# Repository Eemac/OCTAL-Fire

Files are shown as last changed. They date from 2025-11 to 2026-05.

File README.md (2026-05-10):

# OCTAL-Fire
The largest collegiate-built drone in the world!
[OCTAL Website!](https://octalfire.com/)

THE DRONE

## What/Why is this project?
OCTAL is engineered to respond to wildfires faster--and safer--than humans can. Satellites can already detect hotspots with a resolution of ~500ft. Our system will autonomously deploy to the detected hotspot, perform an analysis with 6 visible and infrared-spectrum cameras, and release retardant before the fire has time to get large, saving wildlife, property, and human lives. With four 66Ah, 60V solid-state LiPo battery packs, a 120kg payload, and a projected 40-minute flight time, OCTAL is built smart, tough, and versatile.

## Commands for power-up on the CANable:
- sudo slcand -f -o -s6 -S 115200 -t hw /dev/ttyACMX can0
- sudo ip link set can0 up
- candump can0
- cansniffer -t 0 can0 (-t 0 will display all messages)
- cansend can0

## CANable Web Flasher:
[Link Here](https://canable.io/updater/canable2.html)

## Directory Structure:
### Root

| Path | Description |
|---|---|
| `Firmware/` | Embedded firmware for flight systems, BMS, charger, and CAN communication. |
| `Hardware/` | KiCad PCB designs, fabrication outputs, and mechanical files. |
| `libraries/` | Shared KiCad symbols, footprints, and 3D models. |
| `Software (Sensing)/` | Placeholder for sensing-side software. |
| `Software (Base Station)/` | Placeholder for base station software. |
| `README.md` | Main project overview. |

---

### Firmware/
Main embedded software tree.

| Path | Description |
|---|---|
| `Core/` | Main flight controller firmware. |
| `BMS/` | Battery Management System firmware. |
| `Charger/` | Charger controller firmware. |
| `can_api/` | Python CAN code-generation tools. |
| `libraries/` | Embedded driver libraries. |
| `can_lib.dbc` | CAN database definitions. |
| `x11.dbc` | Additional CAN message definitions. |
| `requirements.txt` | Python dependencies. |
| `run.sh` | Build script. for CAN message functions |

### Firmware/can_api/

Python tooling for generating CAN interfaces.

| File | Description |
|---|---|
| `c_generator.py` | Generates C CAN interface code. |
| `dbc_generator.py` | Generates DBC files. |
| `yaml_handler.py` | Parses YAML definitions. |
| `utils.py` | Shared helper functions. |
| `tests/` | Unit tests for generators. |
| `files/c_templates/` | Templates for generated C code. |

---

### Hardware/

PCB and electrical hardware designs.

| PCB / Project | Description |
|---|---|
| `Core/flight-core` | Main flight controller and avionics motherboard integrating STM32 control, CAN routing, power conversion, Cube interface logic, and system interconnects. |
| `BMS/` | Battery Management System board handling cell monitoring, balancing, thermistor sensing, fan control, and high-voltage battery telemetry. |
| `Power Board/` | High-current power distribution board for routing battery power to vehicle subsystems and monitoring thermal/load conditions. |
| `PowerFet/` | High-side MOSFET switching board for controllable power distribution and subsystem shutdown protection. |
| `Charger/` | Dedicated battery charger controller board with onboard regulators, USB-C input handling, and programmable charge control circuitry. |
| `GroundRing/` | Ground-distribution PCB intended to centralize system grounding and reduce high-current return path issues. |
| `Cube-Flipper/` | Adapter/interface board for Cube flight controller mounting or signal rerouting. |
| `Power Board/Thermistors/` | Small thermistor sensing daughterboard used for distributed temperature monitoring. |
| `Coaster/` | Small auxiliary/demo PCB project included in the repository. |
---

### libraries/

Shared KiCad libraries.

| Path | Description |
|---|---|
| `3DModels/` | STEP/STP component models. |
| `OlinBAD.pretty/` | Custom PCB footprints. |
| `parts/` | Symbols, footprints, datasheets, and docs. |
| `OlinBAD.kicad_sym` | KiCad symbol library. |

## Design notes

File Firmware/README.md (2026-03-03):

# OlinBAD
A BADass Firefighting Drone

## BEFORE LOADING FIRMWARE:
1. Run: `python3 venvStart.py` to create a python virtual environment
2. Start that environment with `source ./venv/bin/activate` (./ being the Firmware directory)
3. Build the dbc intermediate by running `python3 can_api/dbc_generator.py BMS/bms.yml`
3. Build the CAN C files by running `python3 can_api/c_generator.py -y BMS/bms.yml -d out.dbc -c can_api/files/c_templates/can.c -H can_api/files/c_templates/can.h -o BMS`

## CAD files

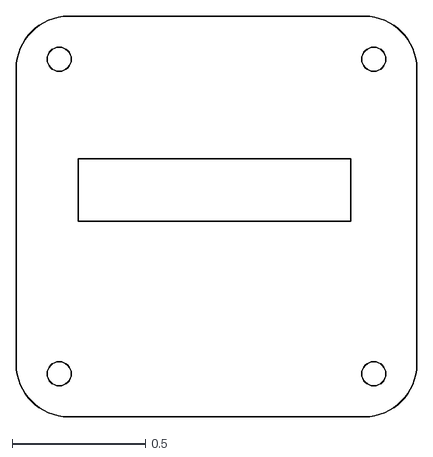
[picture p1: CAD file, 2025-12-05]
Hardware/Core/Bottom Of Cube.dxf
1.50 x 1.50

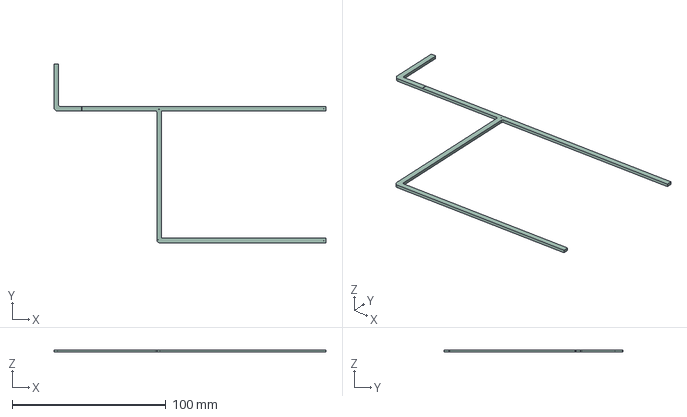
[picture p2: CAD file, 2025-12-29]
Hardware/Power Board/Thermistors/Thermistors.step
177.1 x 116.4 x 1.58 mm
Thermistors_silkscreen
Thermistors_PCB

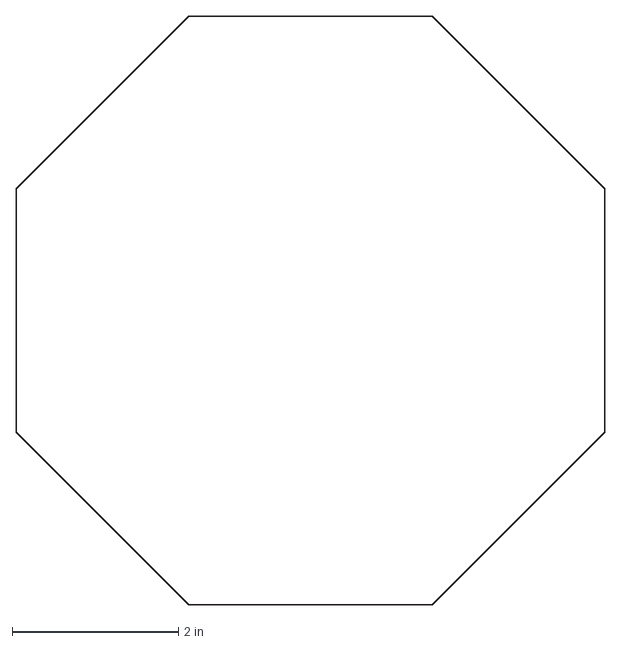
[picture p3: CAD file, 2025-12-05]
Hardware/Core/motherboard.dxf
7.09 x 7.09 in

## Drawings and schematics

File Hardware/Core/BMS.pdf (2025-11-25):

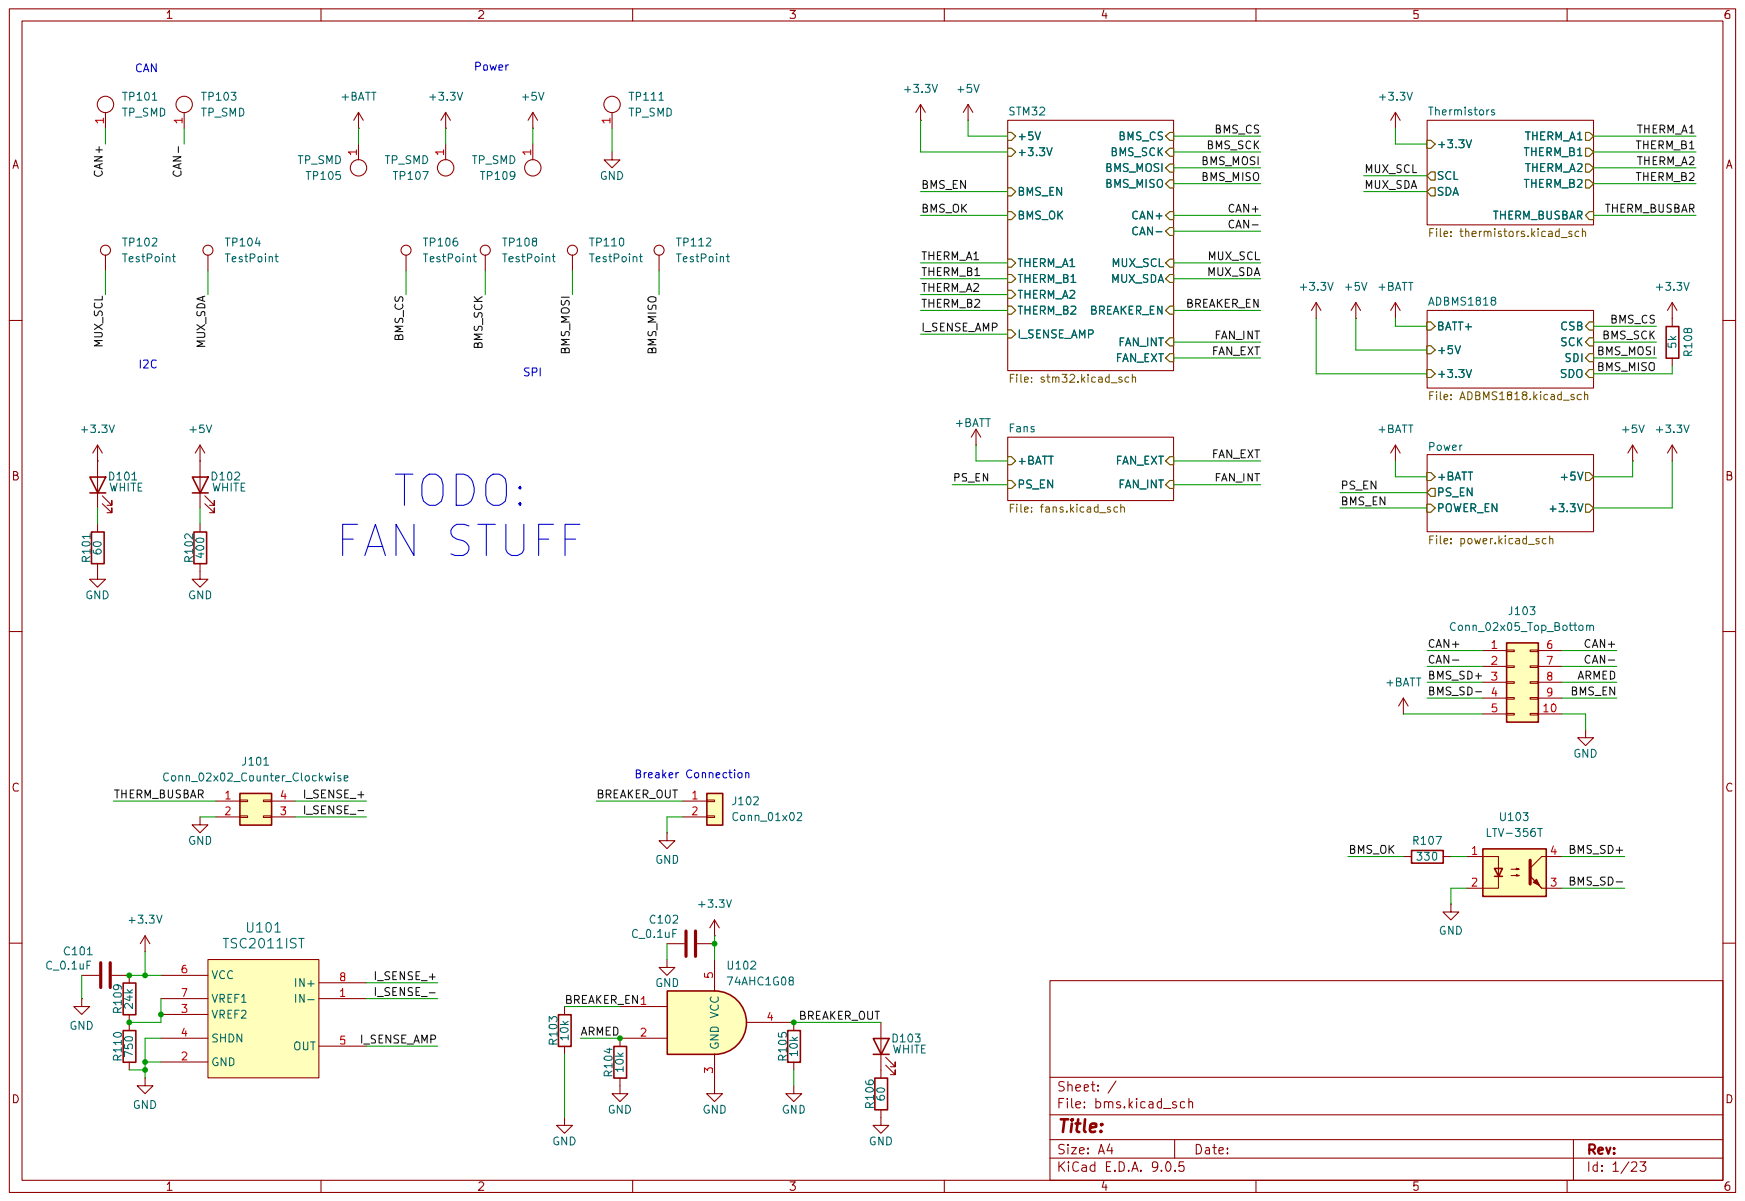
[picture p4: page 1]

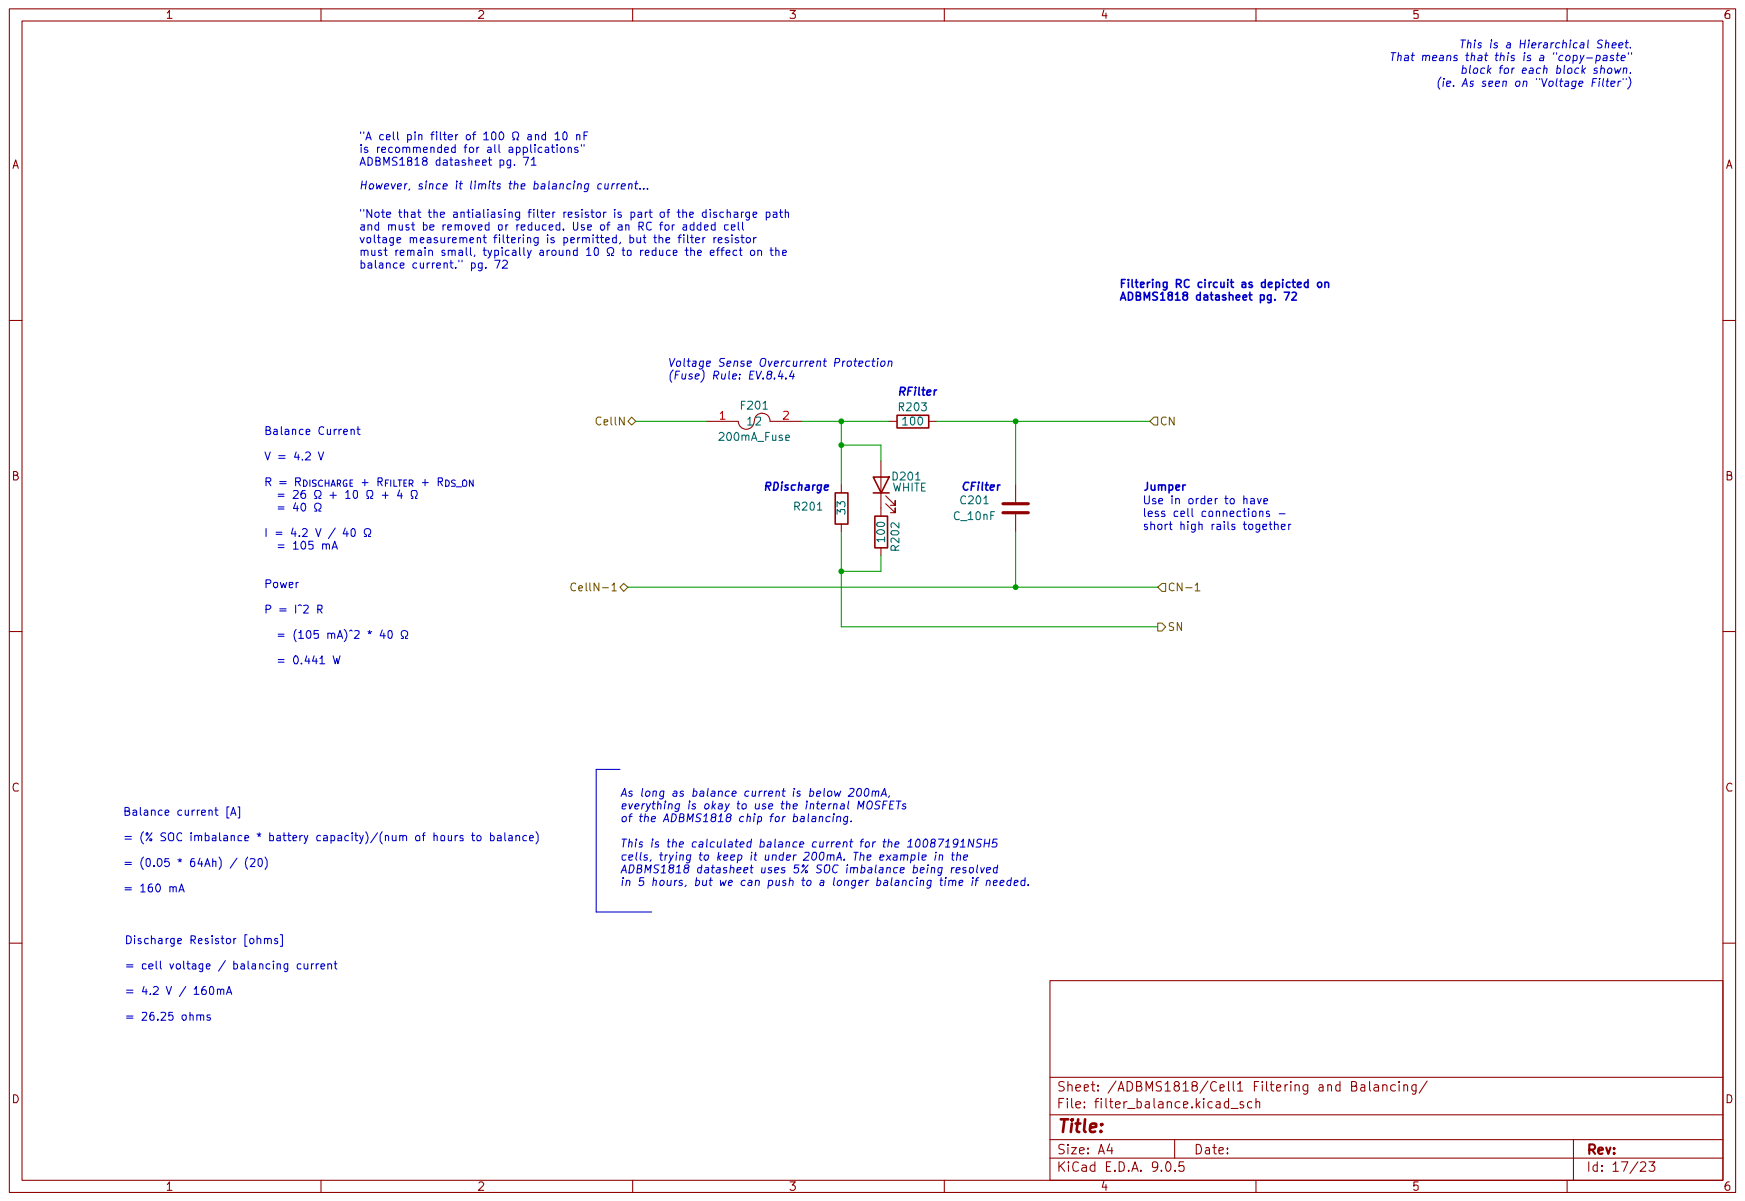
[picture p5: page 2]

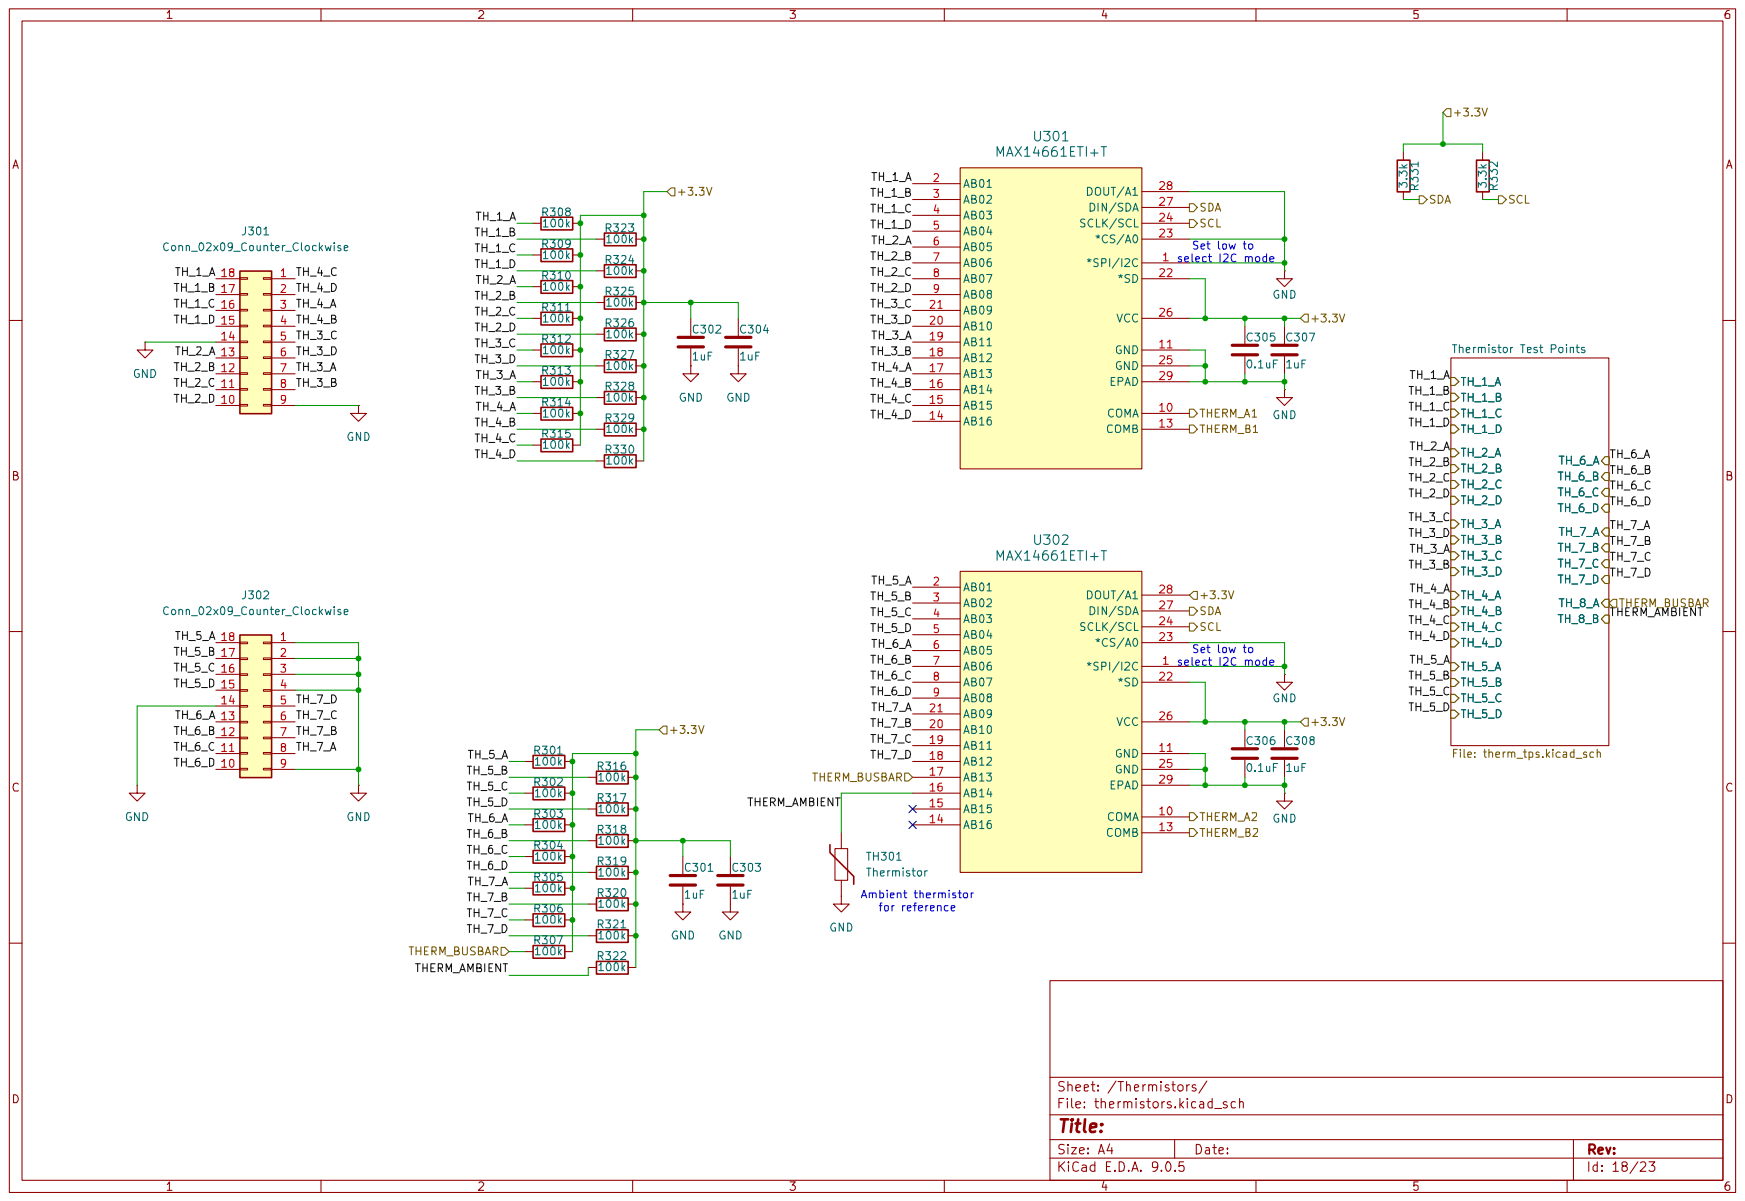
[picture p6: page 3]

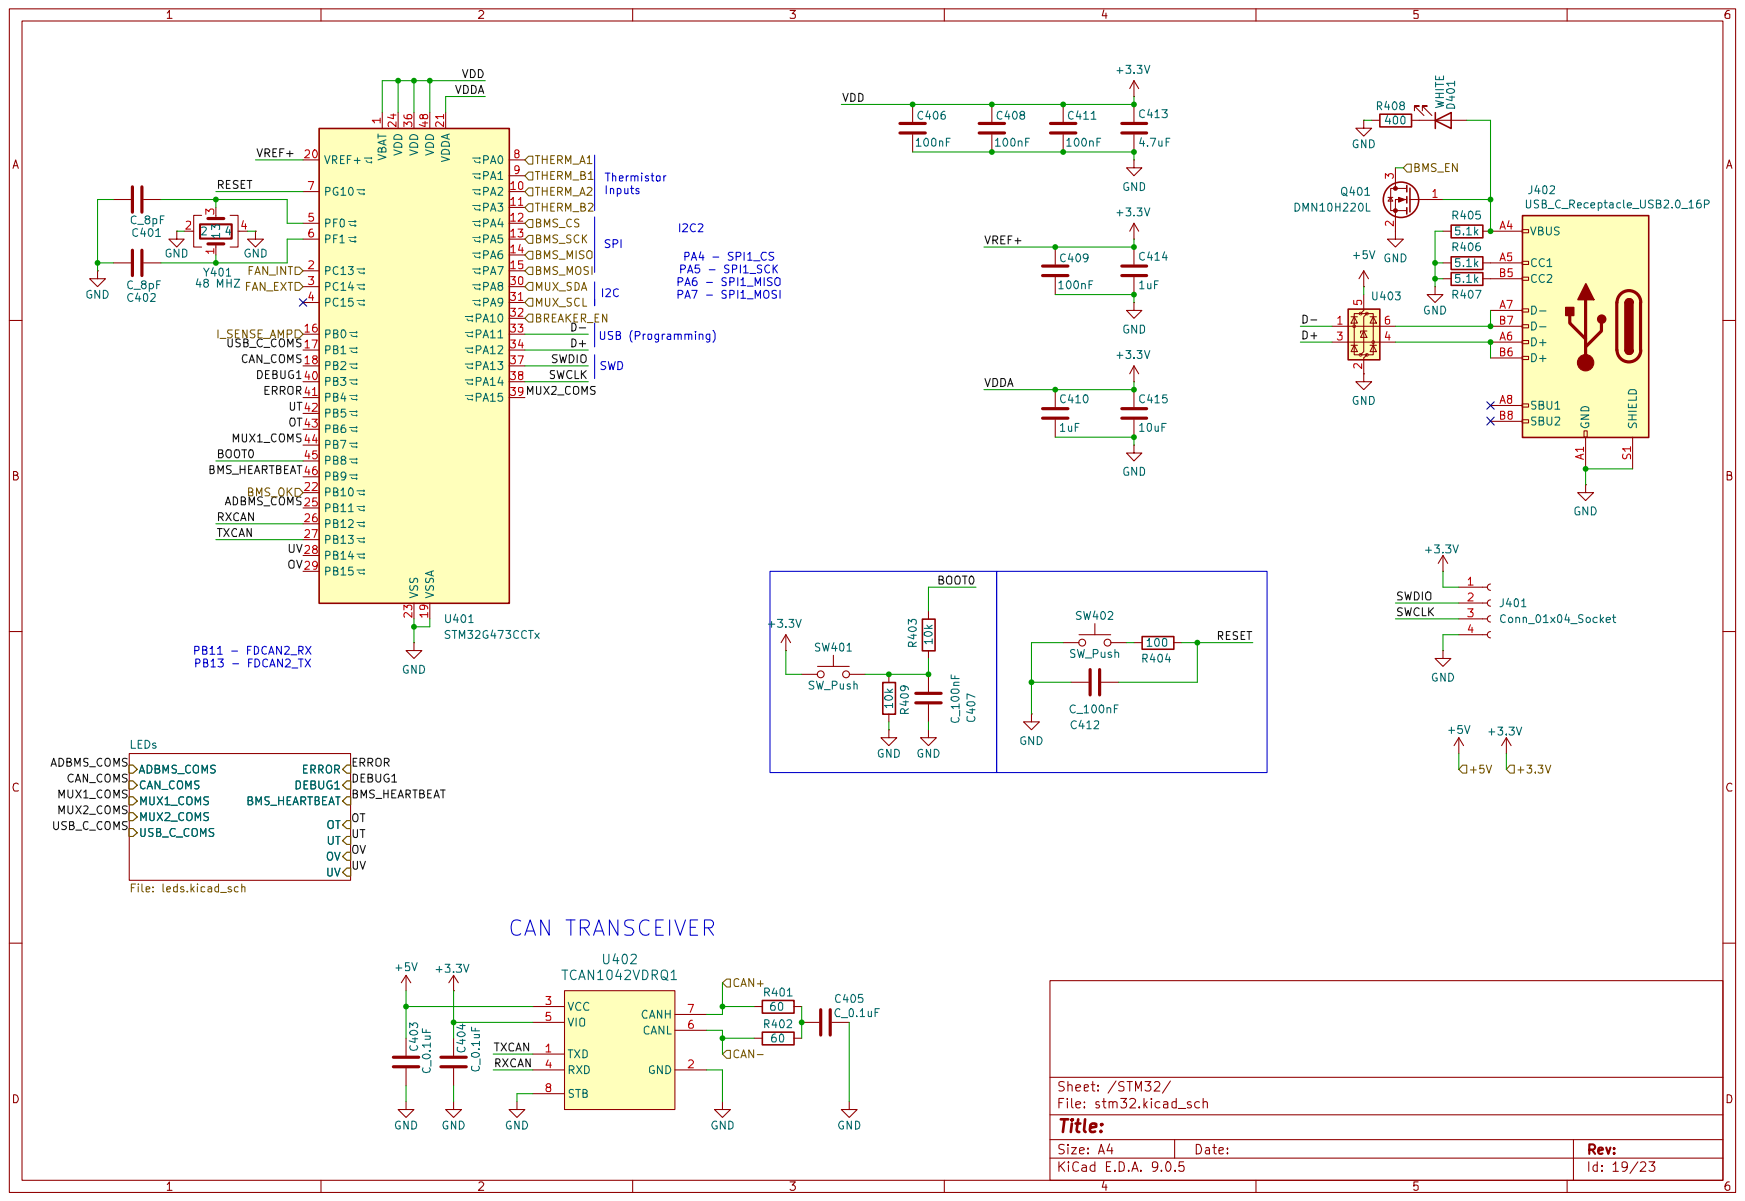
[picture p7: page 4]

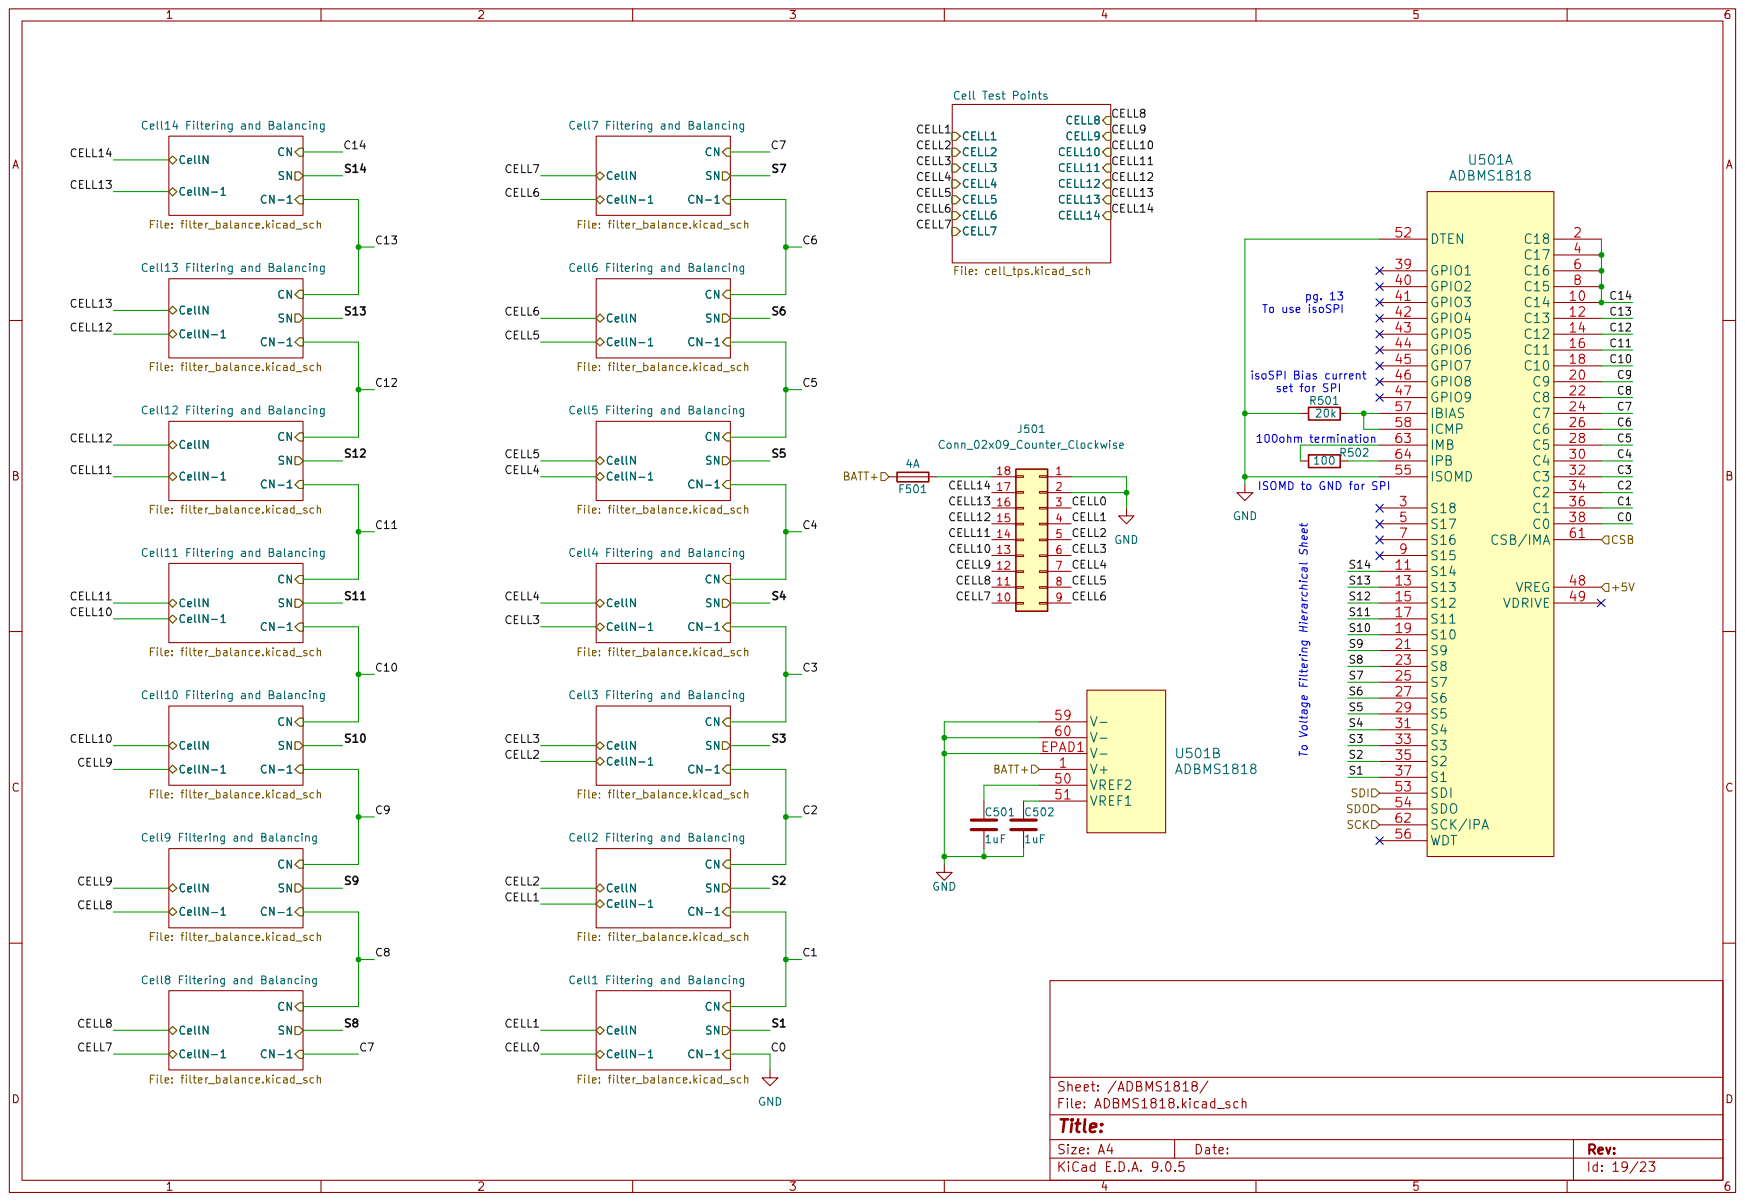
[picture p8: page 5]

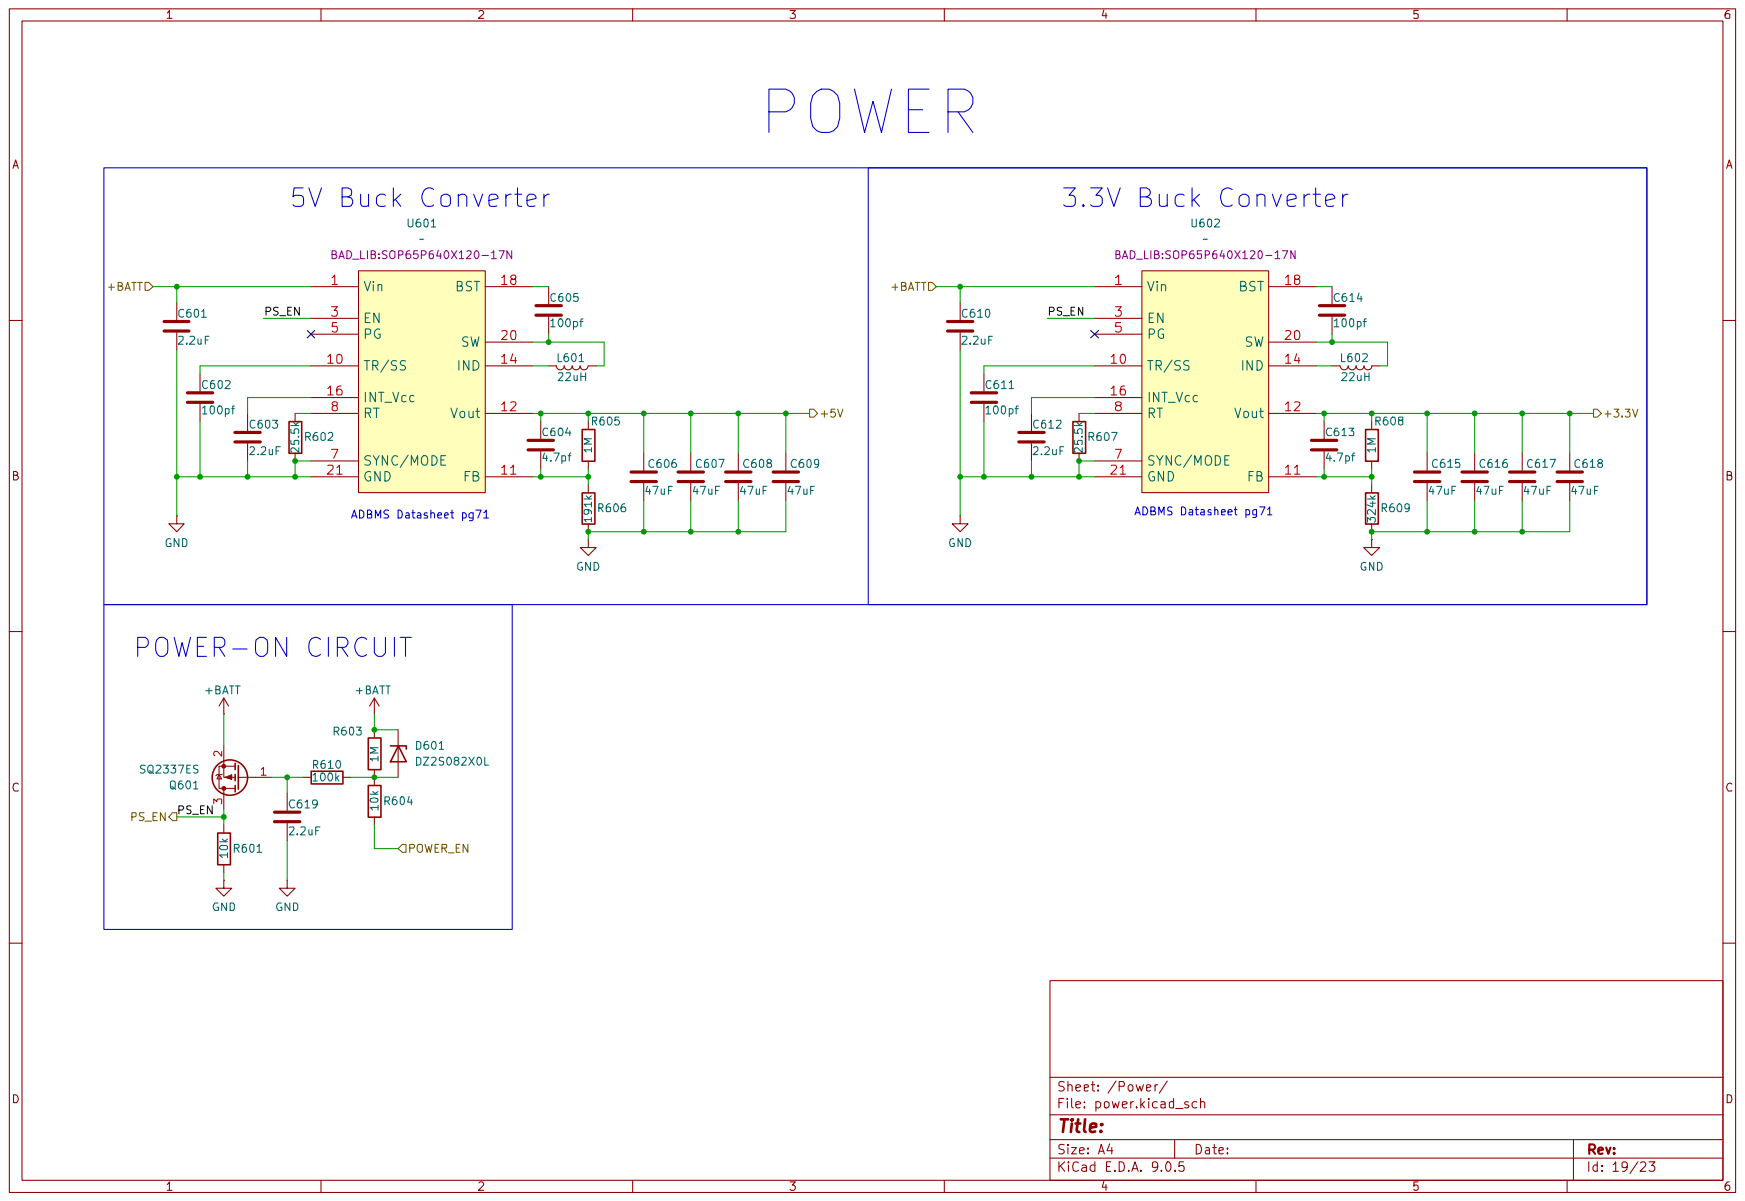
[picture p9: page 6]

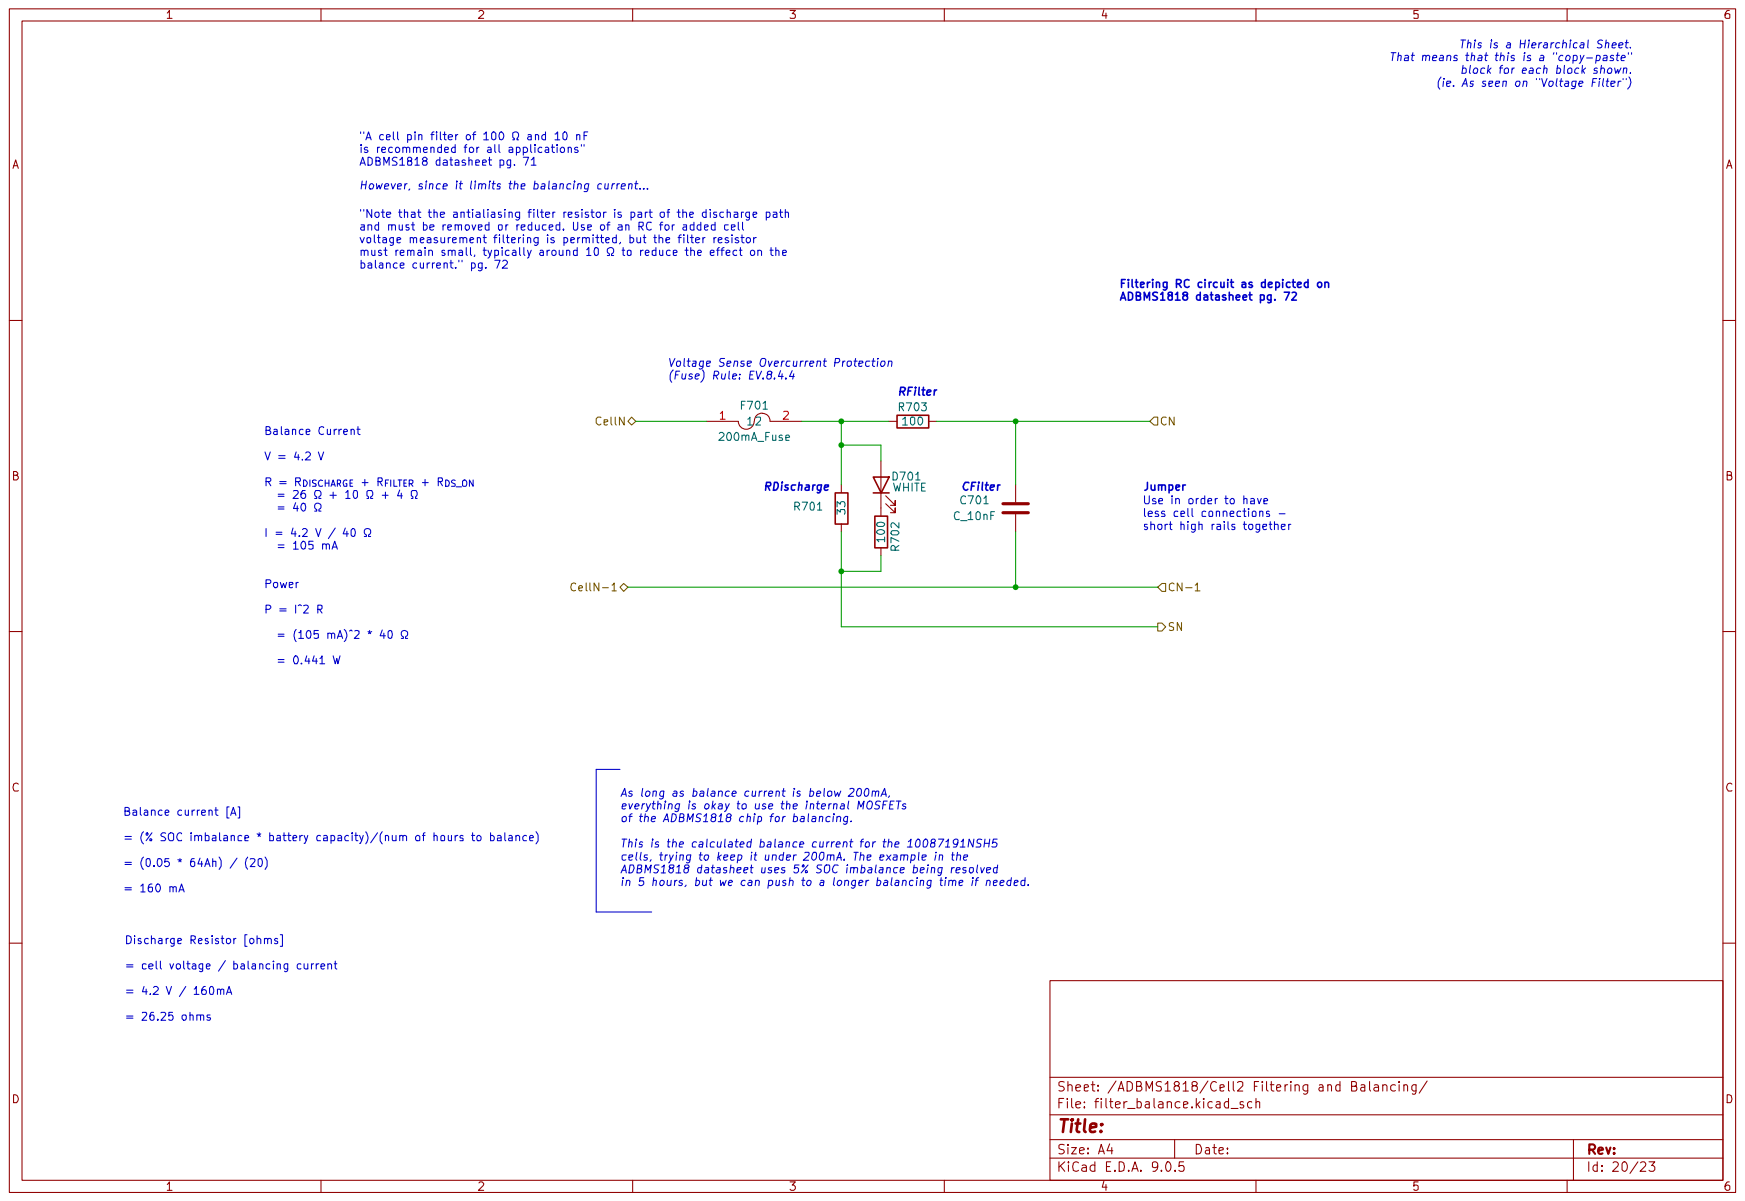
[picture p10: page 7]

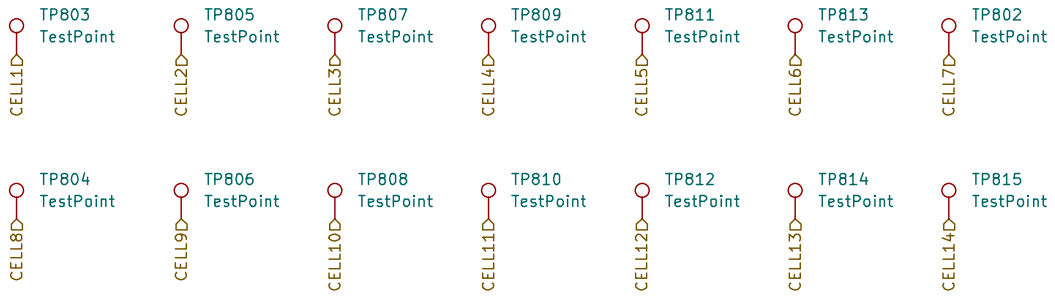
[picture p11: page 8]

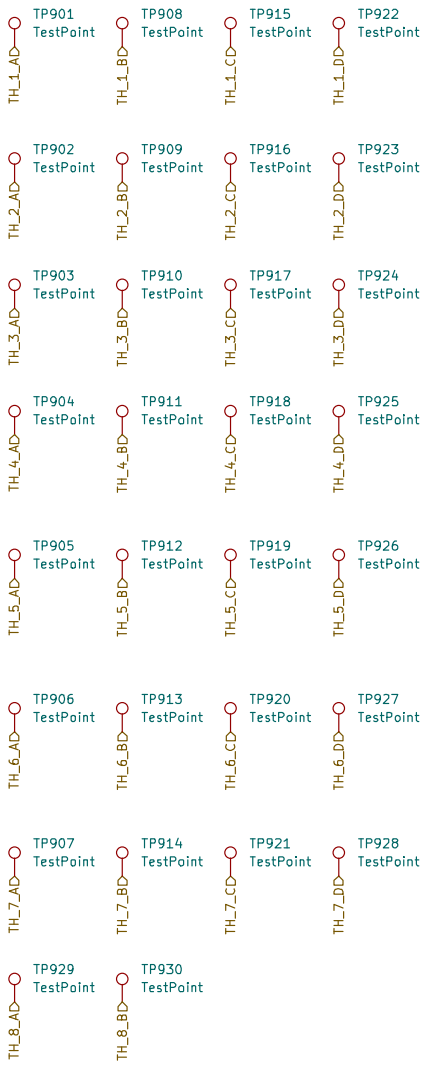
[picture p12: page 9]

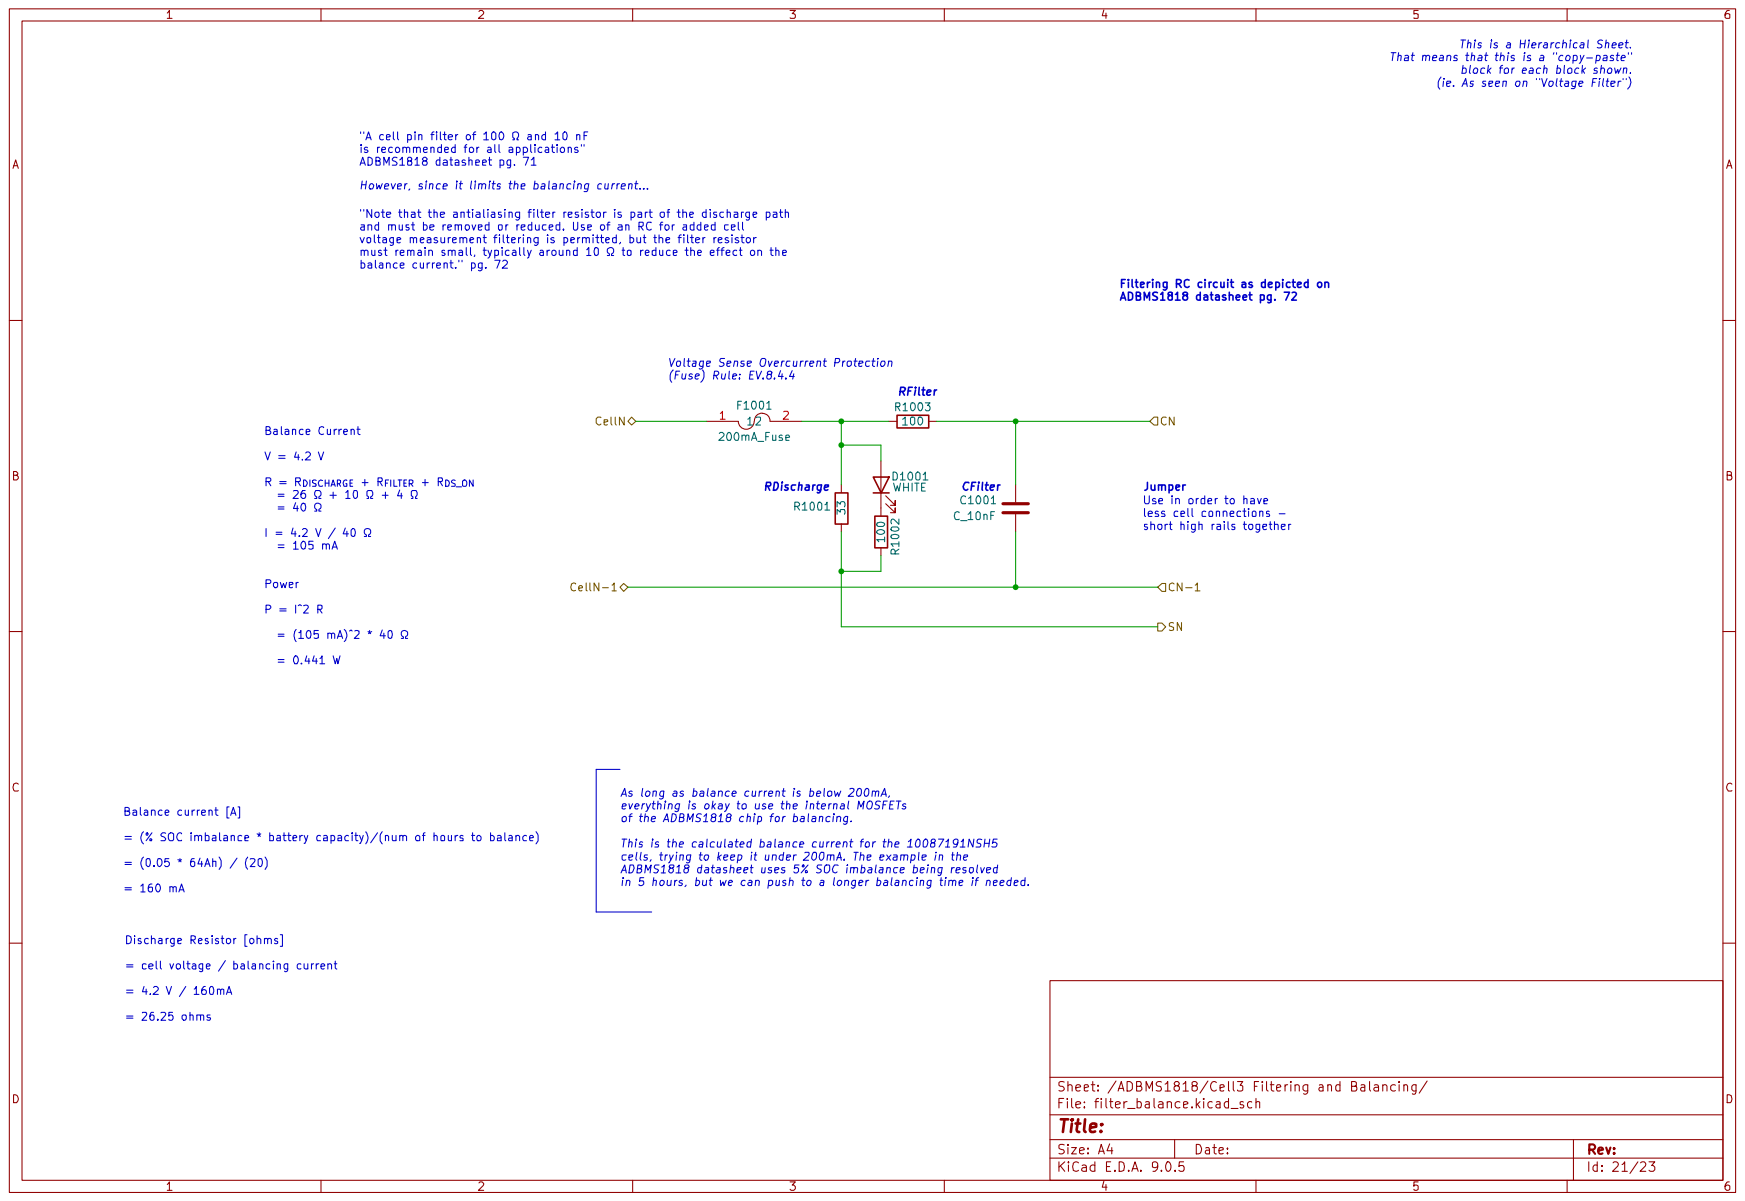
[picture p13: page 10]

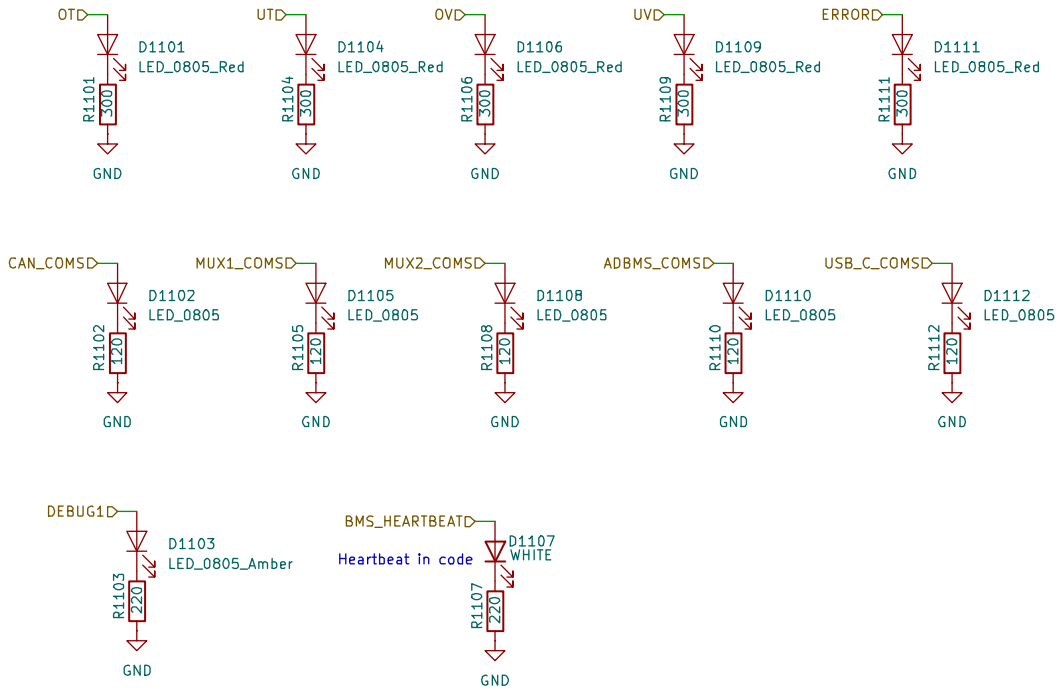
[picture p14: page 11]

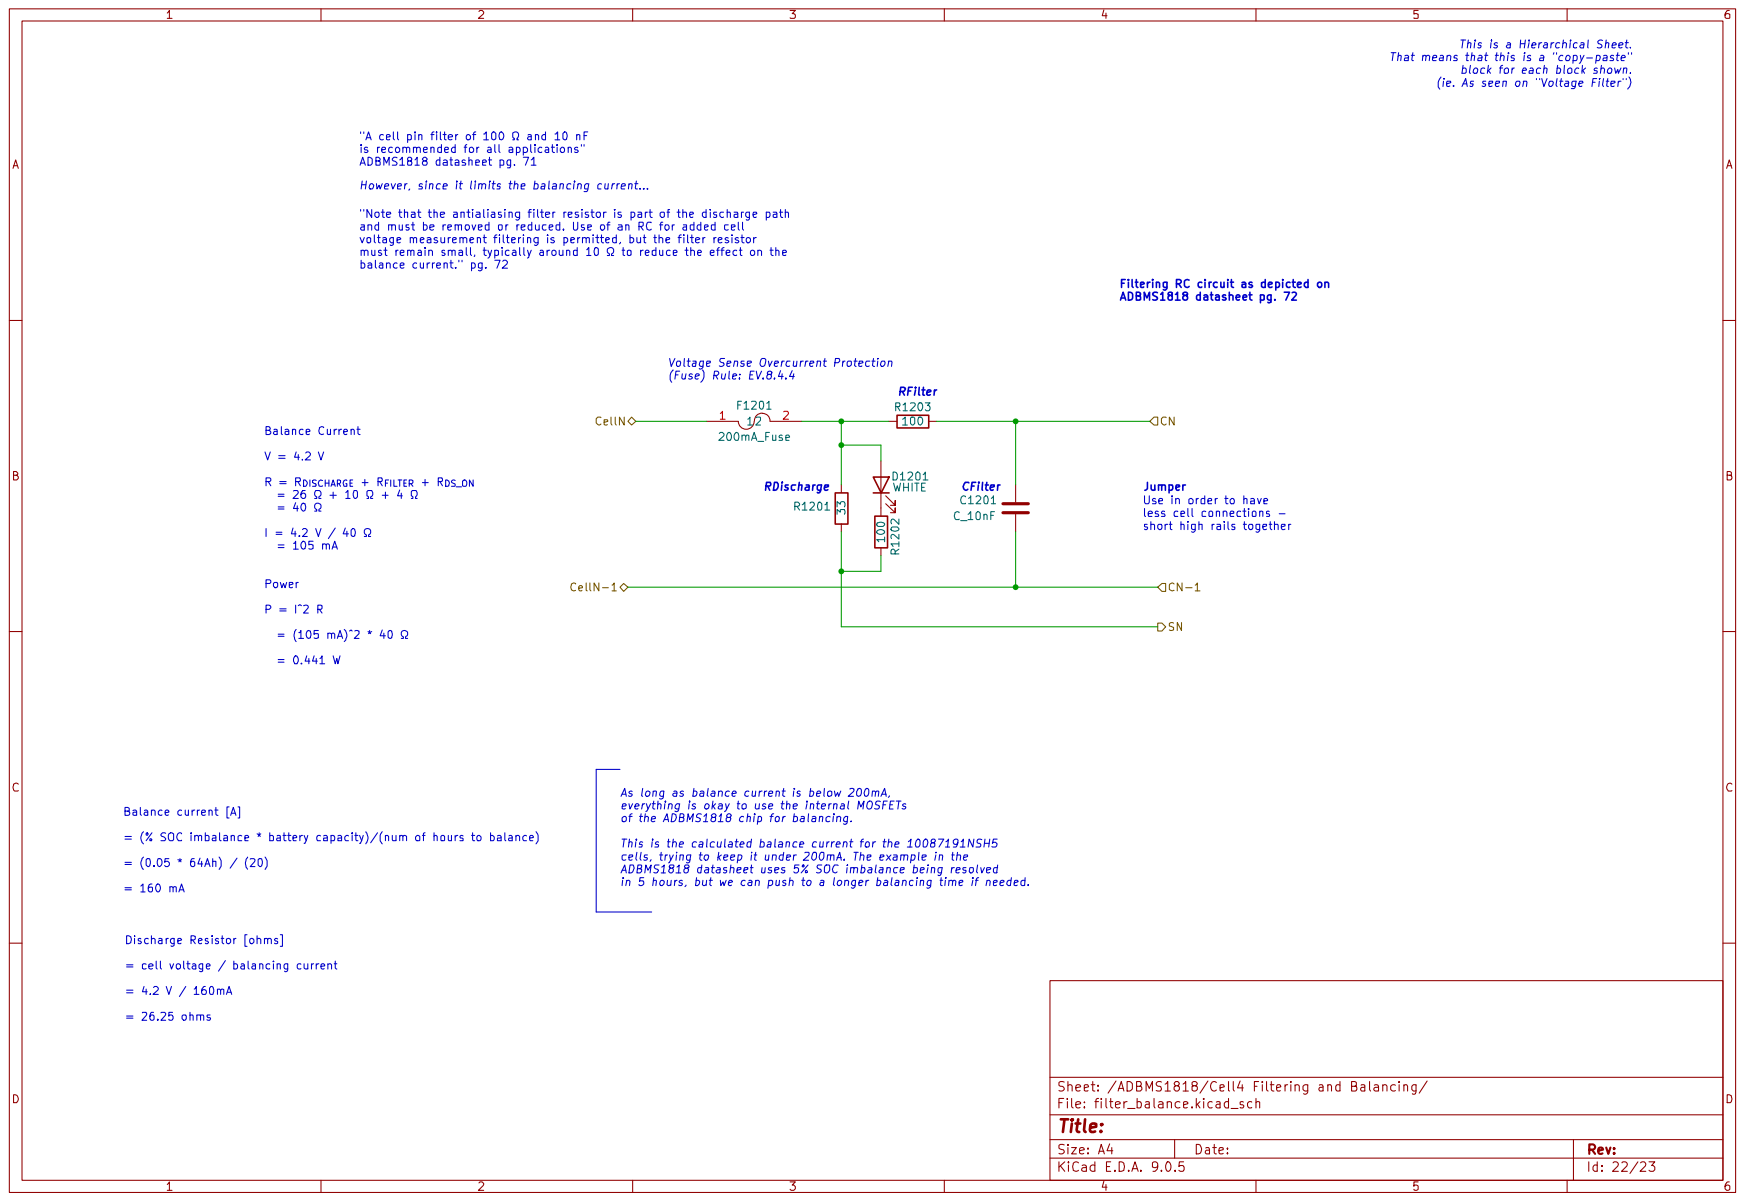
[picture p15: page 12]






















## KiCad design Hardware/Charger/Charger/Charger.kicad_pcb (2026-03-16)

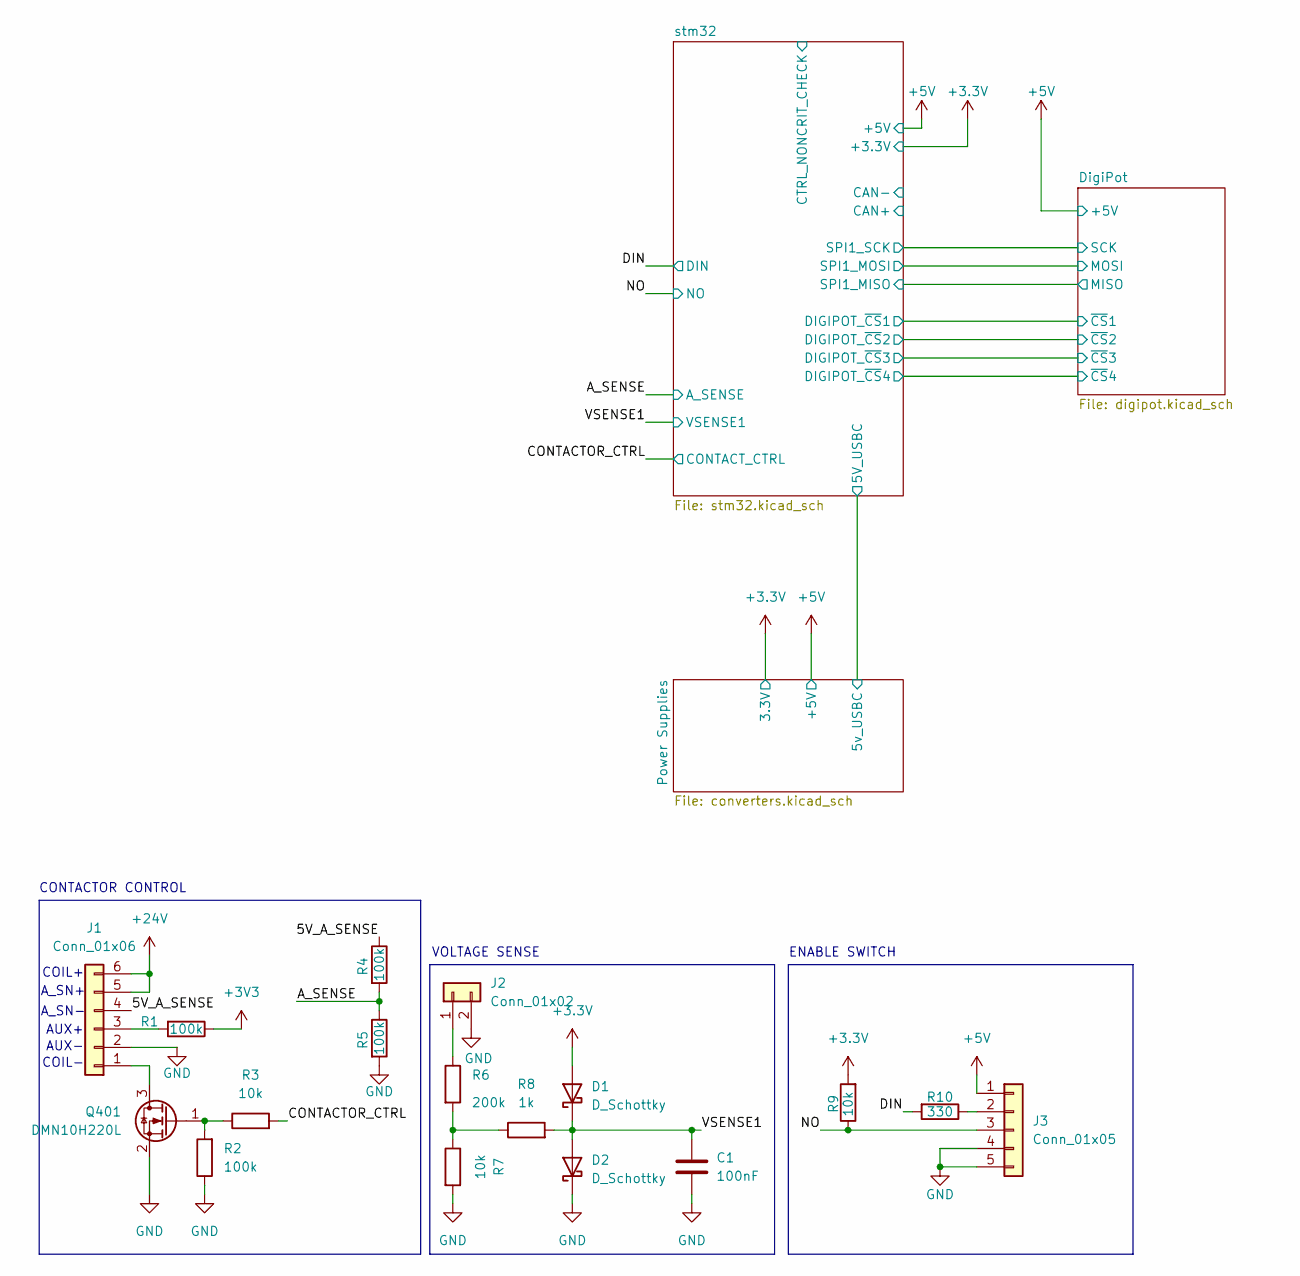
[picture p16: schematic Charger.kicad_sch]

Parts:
C1: 100nF; C_0603_1608Metric
D1, D2: D_Schottky; D_0201_0603Metric
J1: Conn_01x06; Molex_Micro-Fit_3.0_43650-0600_1x06_P3.00mm_Horizontal
J2: Conn_01x02; Molex_Micro-Fit_3.0_43650-0200_1x02_P3.00mm_Horizontal
J3: Conn_01x05; Molex_Micro-Fit_3.0_43650-0500_1x05_P3.00mm_Horizontal
Q401: DMN10H220L; SOT-23
R1, R2, R4, R5: 100k; R_0603_1608Metric
R3, R7, R9: 10k; R_0603_1608Metric
R6: 200k; R_0603_1608Metric
R8: 1k; R_0603_1608Metric
R10: 330; R_0603_1608Metric

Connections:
+3.3V: D1.2 (A), R9.2; also elsewhere on the board
+3V3: R1.1
+5V: J3.1; also elsewhere on the board
+24V: J1.5, J1.6; also elsewhere on the board
/5V_A_SENSE: J1.4, R4.1
/A_SENSE: R4.2, R5.1; also elsewhere on the board
/CONTACTOR_CTRL: R3.2; also elsewhere on the board
/DIN: R10.2; also elsewhere on the board
/NO: J3.3, R9.1; also elsewhere on the board
/VSENSE1: C1.1, D1.1 (K), D2.2 (A), R8.2; also elsewhere on the board
GND: C1.2, D2.1 (K), J1.2, J2.2, J3.4, J3.5, Q401.2 (S), R2.1, R5.2, R7.2; also elsewhere on the board
unnamed: J1.1, Q401.3 (D)
unnamed: J1.3, R1.2
unnamed: J2.1, R6.1
unnamed: J3.2, R10.1
unnamed: Q401.1 (G), R2.2, R3.1
unnamed: R6.2, R7.1, R8.1

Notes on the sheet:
COIL+
CONTACTOR CONTROL
COIL-
A_SN+
AUX-
A_SN-
AUX+
VOLTAGE SENSE
ENABLE SWITCH

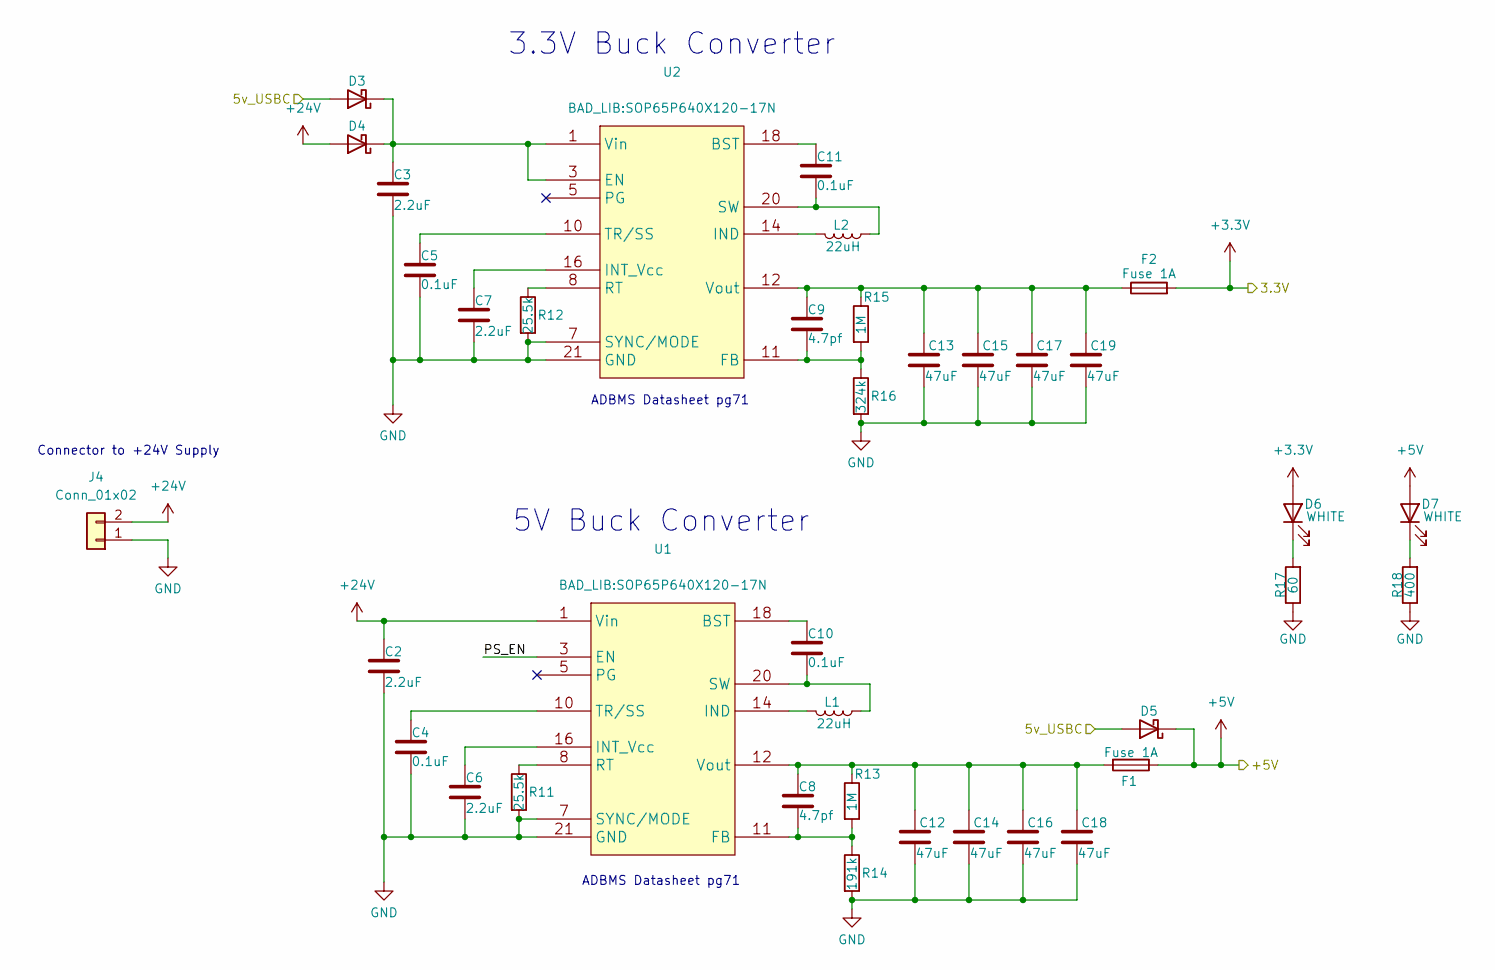
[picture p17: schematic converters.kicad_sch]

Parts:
C2, C3: 2.2uF; C_0805_2012Metric
C4, C5, C10, C11: 0.1uF; C_0603_1608Metric
C6, C7: 2.2uF; C_0603_1608Metric
C8, C9: 4.7pf; C_0603_1608Metric
C12, C13, C14, C15, C16, C17, C18, C19: 47uF; C_1206_3216Metric
D3, D4, D5: 60V 3A; DO-220AA_SS2PH10-M3&slash_84A_VIS; MPN V3P6L-M3/H
D6, D7: WHITE; LED_0805_2012Metric
F1, F2: Fuse 1A; Fuse_1206_3216Metric
J4: Conn_01x02; Molex_Micro-Fit_3.0_43650-0200_1x02_P3.00mm_Horizontal
L1, L2: 22uH; L_12x12mm_H4.5mm
R11, R12: 25.5k; R_0603_1608Metric
R13, R15: 1M; R_0603_1608Metric
R14: 191k; R_0603_1608Metric
R16: 324k; R_0603_1608Metric
R17: 60; R_0603_1608Metric
R18: 400; R_0603_1608Metric
U1, U2: SOP65P640X120-17N

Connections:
+3.3V: D6.2 (A), F2.2; also elsewhere on the board
+5V: D5.1 (K), D7.2 (A), F1.1; also elsewhere on the board
+24V: C2.1, D4.2 (A), J4.2, U1.1 (Vin); also elsewhere on the board
/Power Supplies/5v_USBC: D3.2 (A), D5.2 (A); also elsewhere on the board
/Power Supplies/PS_EN: U1.3 (EN)
GND: C2.2, C3.2, C4.2, C5.2, C6.2, C7.2, C12.2, C13.2, C14.2, C15.2, C16.2, C17.2, C18.2, C19.2, J4.1, R11.2, R12.2, R14.2, R16.2, R17.1, R18.1, U1.7 (SYNC/MODE), U1.21 (GND), U2.7 (SYNC/MODE), U2.21 (GND); also elsewhere on the board
unnamed: C3.1, D3.1 (K), D4.1 (K), U2.1 (Vin), U2.3 (EN)
unnamed: D6.1 (K), R17.2
unnamed: D7.1 (K), R18.2
unnamed: C10.1, U1.18 (BST)
unnamed: C8.2, R13.2, R14.1, U1.11 (FB)
unnamed: L1.2, U1.14 (IND)
unnamed: C6.1, U1.16 (INT_Vcc)
unnamed: R11.1, U1.8 (RT)
unnamed: C10.2, L1.1, U1.20 (SW)
unnamed: C4.1, U1.10 (TR/SS)
unnamed: C8.1, C12.1, C14.1, C16.1, C18.1, F1.2, R13.1, U1.12 (Vout)
unnamed: C11.1, U2.18 (BST)
unnamed: C9.2, R15.2, R16.1, U2.11 (FB)
unnamed: L2.2, U2.14 (IND)
unnamed: C7.1, U2.16 (INT_Vcc)
unnamed: R12.1, U2.8 (RT)
unnamed: C11.2, L2.1, U2.20 (SW)
unnamed: C5.1, U2.10 (TR/SS)
unnamed: C9.1, C13.1, C15.1, C17.1, C19.1, F2.1, R15.1, U2.12 (Vout)

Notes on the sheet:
ADBMS Datasheet pg71
5V Buck Converter
Connector to +24V Supply
3.3V Buck Converter

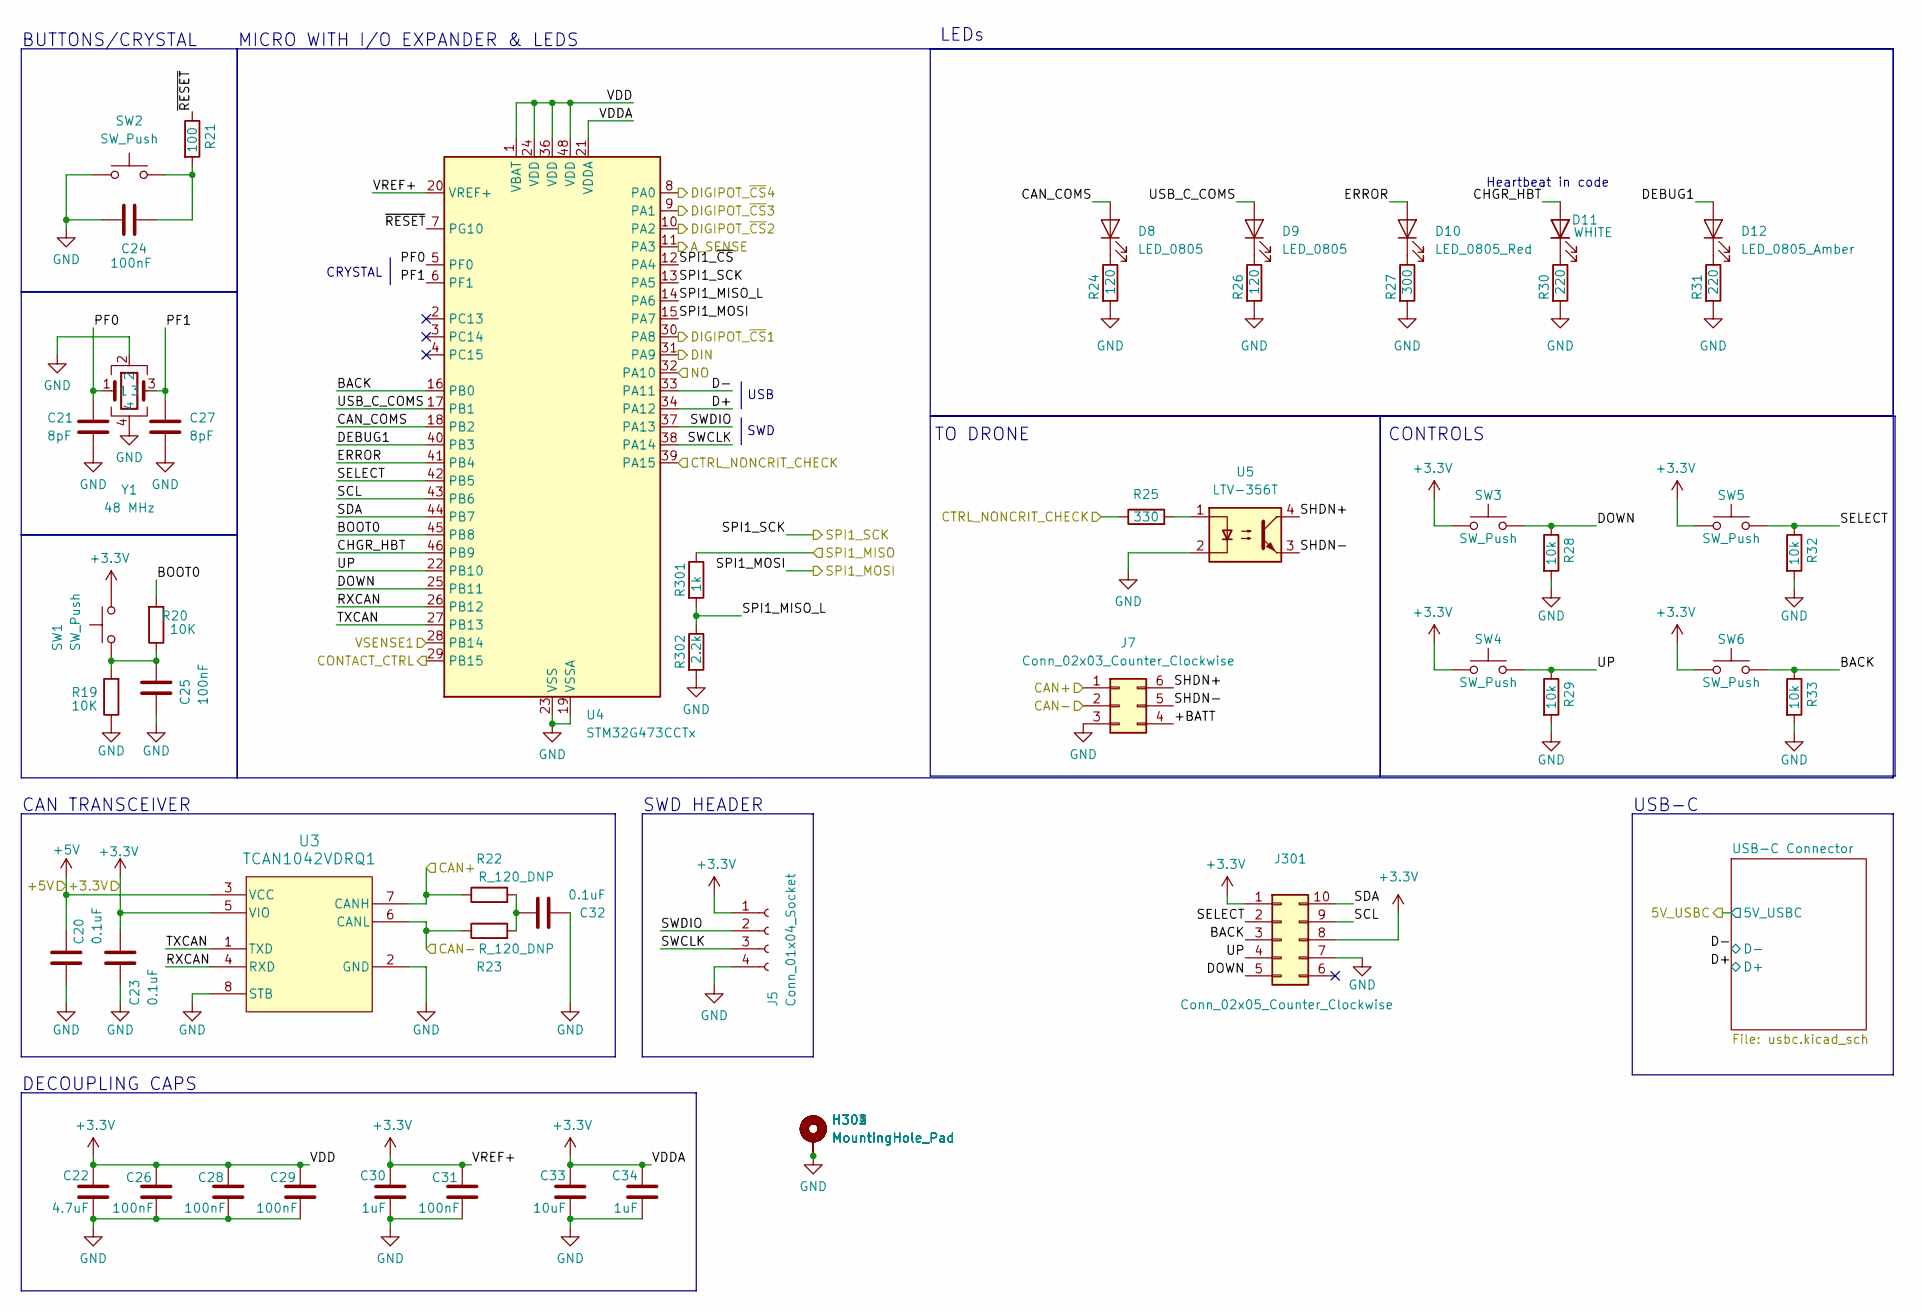
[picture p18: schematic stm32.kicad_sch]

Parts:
C20, C23, C32: 0.1uF; C_0603_1608Metric; MPN C0603C104K5RACTU
C21, C27: 8pF; C_0603_1608Metric
C22: 4.7uF; C_0603_1608Metric; MPN 1276-1052-1-ND
C24, C25, C26, C28, C29, C31: 100nF; C_0603_1608Metric; MPN 1276-6717-1-ND
C30, C34: 1uF; C_0603_1608Metric; MPN 1276-1052-1-ND
C33: 10uF; C_0603_1608Metric; MPN 1276-1052-1-ND
D8, D9: LED_0805; LED_0805_2012Metric; MPN 475-1410-1-ND
D10: LED_0805_Red; LED_0805_2012Metric; MPN 475-1415-1-ND
D11: WHITE; LED_0805_2012Metric
D12: LED_0805_Amber; LED_0805_2012Metric; MPN L71517CT-ND
H301, H302, H303, H304: MountingHole_Pad; MountingHole_3.2mm_M3_Pad_Via
J5: Conn_01x04_Socket; PinSocket_1x04_P2.54mm_Vertical
J7: Conn_02x03_Counter_Clockwise; Molex_Micro-Fit_3.0_43045-0600_2x03_P3.00mm_Horizontal
J301: Conn_02x05_Counter_Clockwise; Molex_Micro-Fit_3.0_43045-1000_2x05_P3.00mm_Horizontal
R19, R20: 10K; R_0603_1608Metric; MPN CRS0805-FX-1002ELFCT-ND
R21: 100; R_0603_1608Metric; MPN CRS0805-FX-1002ELFCT-ND
R22, R23: R_120_DNP; R_0603_1608Metric; MPN 667-ERJ-6ENF1200V
R24, R26: 120; R_0603_1608Metric; MPN 667-ERJ-6ENF1200V
R25: 330; R_0603_1608Metric
R27: 300; R_0603_1608Metric; MPN 667-ERJ-6ENF1200V
R28, R29, R32, R33: 10k; R_0603_1608Metric; MPN CRS0805-FX-1002ELFCT-ND
R30, R31: 220; R_0603_1608Metric; MPN 667-ERJ-6ENF1200V
R301: 1k; R_0603_1608Metric; MPN 667-ERJ-6ENF1200V
R302: 2.2k; R_0603_1608Metric; MPN 667-ERJ-6ENF1200V
SW1, SW2, SW3, SW4, SW5, SW6: SW_Push; SW_Push_1P1T_NO_CK_KMR2
U3: TCAN1042VDRQ1; D0008A_M
U4: STM32G473CCTx; LQFP-48_7x7mm_P0.5mm
U5: LTV-356T; SO-4_4.4x3.6mm_P2.54mm
Y1: 48 MHz; Crystal_SMD_SeikoEpson_FA238-4Pin_3.2x2.5mm; MPN 7M48072002

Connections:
+3.3V: C22.1, C23.1, C26.1, C28.1, C29.1, C30.1, C31.1, C33.1, C34.1, J5.1, J301.1, J301.8, SW1.1, SW3.1, SW4.1, SW5.1, SW6.1, U3.5 (VIO), U4.1 (VBAT), U4.20 (VREF+), U4.21 (VDDA), U4.24 (VDD), U4.36 (VDD), U4.48 (VDD); also elsewhere on the board
+5V: C20.1, U3.3 (VCC); also elsewhere on the board
/A_SENSE: U4.11 (PA3); also elsewhere on the board
/CONTACTOR_CTRL: U4.29 (PB15); also elsewhere on the board
/DIN: U4.31 (PA9); also elsewhere on the board
/DigiPot/MISO: R301.1; also elsewhere on the board
/DigiPot/~CS1: U4.30 (PA8); also elsewhere on the board
/DigiPot/~CS2: U4.10 (PA2); also elsewhere on the board
/DigiPot/~CS3: U4.9 (PA1); also elsewhere on the board
/DigiPot/~CS4: U4.8 (PA0); also elsewhere on the board
/NO: U4.32 (PA10); also elsewhere on the board
/VSENSE1: U4.28 (PB14); also elsewhere on the board
/stm32/+BATT: J7.4
/stm32/BACK: J301.3, R33.1, SW6.2, U4.16 (PB0)
/stm32/BOOT0: R20.2, U4.45 (PB8)
/stm32/CAN+: J7.1, R22.1, U3.7 (CANH)
/stm32/CAN-: J7.2, R23.1, U3.6 (CANL)
/stm32/CAN_COMS: D8.2 (A), U4.18 (PB2)
/stm32/CHGR_HBT: D11.2 (A), U4.46 (PB9)
/stm32/CTRL_NONCRIT_CHECK: R25.1, U4.39 (PA15)
/stm32/D+: U4.34 (PA12); also elsewhere on the board
/stm32/D-: U4.33 (PA11); also elsewhere on the board
/stm32/DEBUG1: D12.2 (A), U4.40 (PB3)
/stm32/DOWN: J301.5, R28.1, SW3.2, U4.25 (PB11)
/stm32/ERROR: D10.2 (A), U4.41 (PB4)
/stm32/PF0: C21.1, U4.5 (PF0), Y1.1
/stm32/PF1: C27.1, U4.6 (PF1), Y1.3
/stm32/RXCAN: U3.4 (RXD), U4.26 (PB12)
/stm32/SCL: J301.9, U4.43 (PB6)
/stm32/SDA: J301.10, U4.44 (PB7)
/stm32/SELECT: J301.2, R32.1, SW5.2, U4.42 (PB5)
/stm32/SHDN+: J7.6, U5.4
/stm32/SHDN-: J7.5, U5.3
/stm32/SPI1_MISO_L: R301.2, R302.1, U4.14 (PA6)
/stm32/SPI1_MOSI: U4.15 (PA7); also elsewhere on the board
/stm32/SPI1_SCK: U4.13 (PA5); also elsewhere on the board
/stm32/SPI1_~CS: U4.12 (PA4)
/stm32/SWCLK: J5.3, U4.38 (PA14)
/stm32/SWDIO: J5.2, U4.37 (PA13)
/stm32/TXCAN: U3.1 (TXD), U4.27 (PB13)
/stm32/UP: J301.4, R29.1, SW4.2, U4.22 (PB10)
/stm32/USB_C_COMS: D9.2 (A), U4.17 (PB1)
/stm32/~RESET: R21.1, U4.7 (PG10)
GND: C20.2, C21.2, C22.2, C23.2, C24.1, C25.2, C26.2, C27.2, C28.2, C29.2, C30.2, C31.2, C32.2, C33.2, C34.2, H301.1, H302.1, H303.1, H304.1, J5.4, J7.3, J301.7, R19.1, R24.2, R26.2, R27.2, R28.2, R29.2, R30.2, R31.2, R32.2, R33.2, R302.2, SW2.1, U3.2 (GND), U3.8 (STB), U4.19 (VSSA), U4.23 (VSS), U4.35 (VSS), U4.47 (VSS), U5.2, Y1.2, Y1.4; also elsewhere on the board
unnamed: C24.2, R21.2, SW2.2
unnamed: C25.1, R19.2, R20.1, SW1.2
unnamed: C32.1, R22.2, R23.2
unnamed: D8.1 (K), R24.1
unnamed: D9.1 (K), R26.1
unnamed: D10.1 (K), R27.1
unnamed: D11.1 (K), R30.1
unnamed: D12.1 (K), R31.1
unnamed: R25.2, U5.1

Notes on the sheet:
Heartbeat in code
CRYSTAL
SWD HEADER
MICRO WITH I/O EXPANDER & LEDS
DECOUPLING CAPS
LEDs
CONTROLS
BUTTONS/CRYSTAL
USB
TO DRONE
USB-C
CAN TRANSCEIVER
SWD

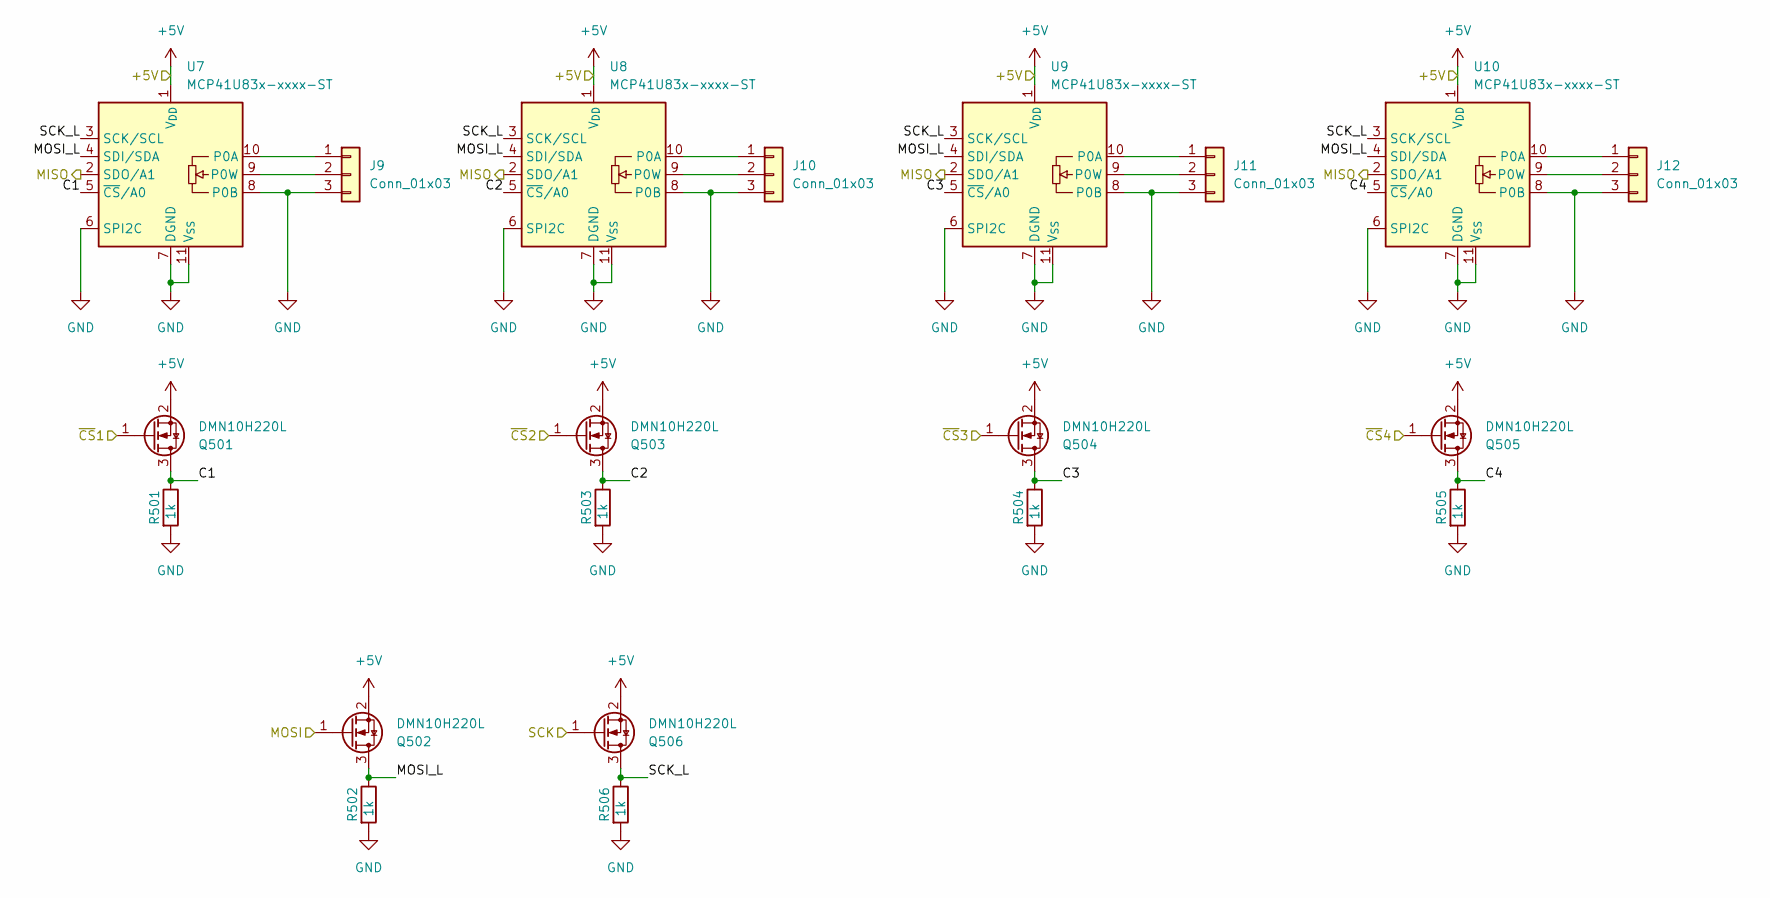
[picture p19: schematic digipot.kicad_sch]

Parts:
J9, J10, J11, J12: Conn_01x03; Molex_Micro-Fit_3.0_43650-0300_1x03_P3.00mm_Horizontal
Q501, Q502, Q503, Q504, Q505, Q506: DMN10H220L; SOT-23
R501, R502, R503, R504, R505, R506: 1k; R_0603_1608Metric; MPN 667-ERJ-6ENF1200V
U7, U8, U9, U10: MCP41U83x-xxxx-ST; TSSOP-14_4.4x5mm_P0.65mm

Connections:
+5V: Q501.2 (S), Q502.2 (S), Q503.2 (S), Q504.2 (S), Q505.2 (S), Q506.2 (S), U7.1 (V_{DD}), U8.1 (V_{DD}), U9.1 (V_{DD}), U10.1 (V_{DD}); also elsewhere on the board
/DigiPot/C1: Q501.3 (D), R501.1, U7.5 (~CS/A0)
/DigiPot/C2: Q503.3 (D), R503.1, U8.5 (~CS/A0)
/DigiPot/C3: Q504.3 (D), R504.1, U9.5 (~CS/A0)
/DigiPot/C4: Q505.3 (D), R505.1, U10.5 (~CS/A0)
/DigiPot/MISO: U7.2 (SDO/A1), U8.2 (SDO/A1), U9.2 (SDO/A1), U10.2 (SDO/A1); also elsewhere on the board
/DigiPot/MOSI_L: Q502.3 (D), R502.1, U7.4 (SDI/SDA), U8.4 (SDI/SDA), U9.4 (SDI/SDA), U10.4 (SDI/SDA)
/DigiPot/SCK_L: Q506.3 (D), R506.1, U7.3 (SCK/SCL), U8.3 (SCK/SCL), U9.3 (SCK/SCL), U10.3 (SCK/SCL)
/DigiPot/~CS1: Q501.1 (G); also elsewhere on the board
/DigiPot/~CS2: Q503.1 (G); also elsewhere on the board
/DigiPot/~CS3: Q504.1 (G); also elsewhere on the board
/DigiPot/~CS4: Q505.1 (G); also elsewhere on the board
/stm32/SPI1_MOSI: Q502.1 (G); also elsewhere on the board
/stm32/SPI1_SCK: Q506.1 (G); also elsewhere on the board
GND: J9.3, J10.3, J11.3, J12.3, R501.2, R502.2, R503.2, R504.2, R505.2, R506.2, U7.6 (SPI2C), U7.7 (DGND), U7.8 (P0B), U7.11 (V_{SS}), U8.6 (SPI2C), U8.7 (DGND), U8.8 (P0B), U8.11 (V_{SS}), U9.6 (SPI2C), U9.7 (DGND), U9.8 (P0B), U9.11 (V_{SS}), U10.6 (SPI2C), U10.7 (DGND), U10.8 (P0B), U10.11 (V_{SS}); also elsewhere on the board
unnamed: J9.1, U7.10 (P0A)
unnamed: J9.2, U7.9 (P0W)
unnamed: J10.1, U8.10 (P0A)
unnamed: J10.2, U8.9 (P0W)
unnamed: J11.1, U9.10 (P0A)
unnamed: J11.2, U9.9 (P0W)
unnamed: J12.1, U10.10 (P0A)
unnamed: J12.2, U10.9 (P0W)

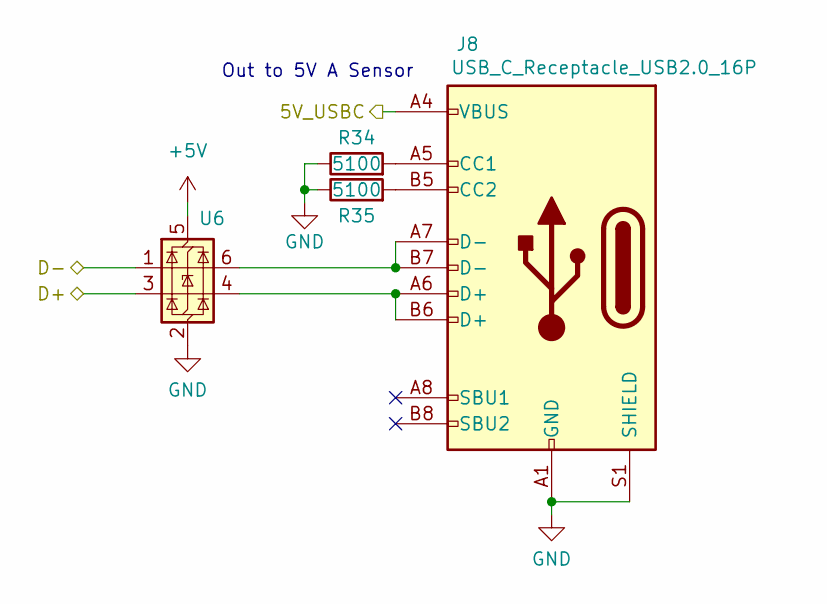
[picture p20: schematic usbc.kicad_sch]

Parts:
J8: USB_C_Receptacle_USB2.0_16P; USB_C_Receptacle_GCT_USB4105-xx-A_16P_TopMnt_Horizontal
R34, R35: 5100; R_0603_1608Metric
U6: USBLC6-2SC6; SOT-23-6

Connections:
+5V: U6.5 (VBUS); also elsewhere on the board
/Power Supplies/5v_USBC: J8.A4 (VBUS), J8.A9 (VBUS), J8.B4 (VBUS), J8.B9 (VBUS); also elsewhere on the board
/stm32/D+: U6.3 (I/O2); also elsewhere on the board
/stm32/D-: U6.1 (I/O1); also elsewhere on the board
GND: J8.A1 (GND), J8.A12 (GND), J8.B1 (GND), J8.B12 (GND), J8.S1 (SHIELD), R34.1, R35.1, U6.2 (GND); also elsewhere on the board
unnamed: J8.A5 (CC1), R34.2
unnamed: J8.B5 (CC2), R35.2
unnamed: J8.A6 (D+), J8.B6 (D+), U6.4 (I/O2)
unnamed: J8.A7 (D-), J8.B7 (D-), U6.6 (I/O1)

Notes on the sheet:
Out to 5V A Sensor

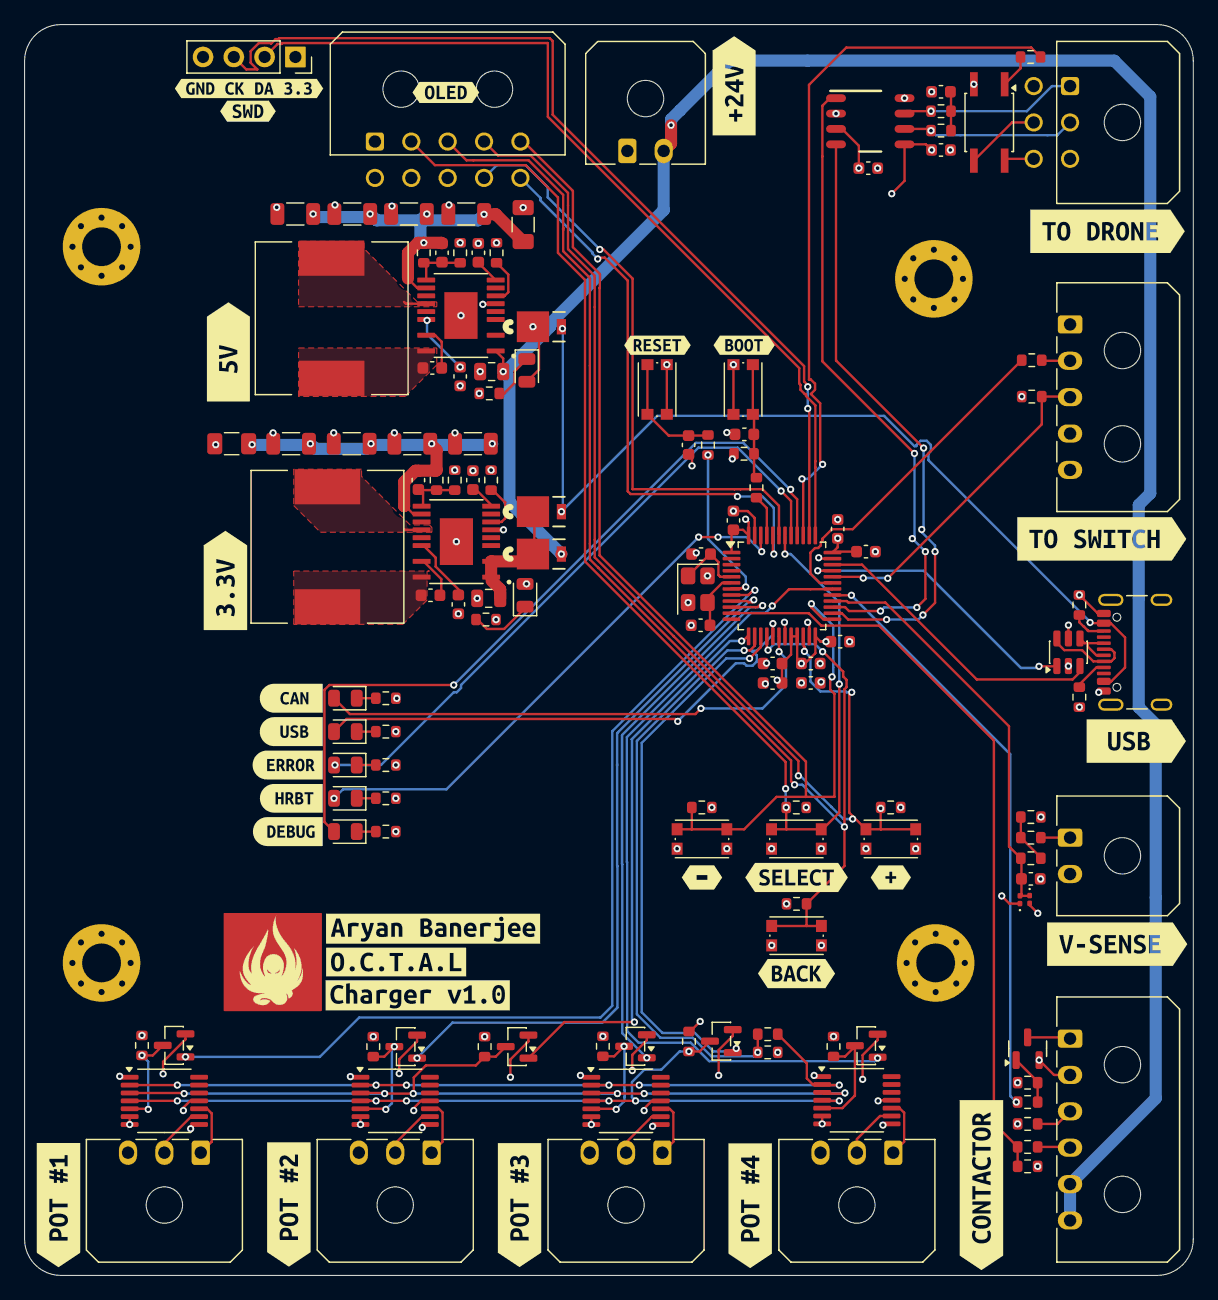
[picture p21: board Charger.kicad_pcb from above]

Board: 4 copper layers, 96.4 x 103.2 mm, 162 parts (0 on the bottom side), 97 nets.

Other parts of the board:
kibuzzard-69B34D34: G***; kibuzzard-69B34D34
kibuzzard-69B34D41: G***; kibuzzard-69B34D41
kibuzzard-69B34DA5: G***; kibuzzard-69B34DA5
kibuzzard-69B34DB2: G***; kibuzzard-69B34DB2
kibuzzard-69B34DBF: G***; kibuzzard-69B34DBF
kibuzzard-69B34DC8: G***; kibuzzard-69B34DC8
kibuzzard-69B34E6D: G***; kibuzzard-69B34E6D
kibuzzard-69B34E29: G***; kibuzzard-69B34E29
kibuzzard-69B34E60: G***; kibuzzard-69B34E60
kibuzzard-69B36C6C: G***; kibuzzard-69B36C6C
kibuzzard-69B36C7B: G***; kibuzzard-69B36C7B
kibuzzard-69B36C96: G***; kibuzzard-69B36C96
kibuzzard-69B36CA5: G***; kibuzzard-69B36CA5
kibuzzard-69B36CC2: G***; kibuzzard-69B36CC2
kibuzzard-69B81BEB: G***; kibuzzard-69B81BEB
kibuzzard-69B81C0B: G***; kibuzzard-69B81C0B
kibuzzard-69B81D82: G***; kibuzzard-69B81D82
kibuzzard-69B81DBD: G***; kibuzzard-69B81DBD
kibuzzard-69B81DEB: G***; kibuzzard-69B81DEB
kibuzzard-69B81E61: G***; kibuzzard-69B81E61
kibuzzard-69B81E77: G***; kibuzzard-69B81E77
kibuzzard-69B821F4: G***; kibuzzard-69B821F4
kibuzzard-69B824A2: G***; kibuzzard-69B824A2
kibuzzard-69B8247B: G***; kibuzzard-69B8247B
kibuzzard-69B82222: G***; kibuzzard-69B82222
kibuzzard-69B82233: G***; kibuzzard-69B82233
kibuzzard-69B82281: G***; kibuzzard-69B82281
kibuzzard-690FB70C: G***; kibuzzard-690FB70C
kibuzzard-690FB638: G***; kibuzzard-690FB638

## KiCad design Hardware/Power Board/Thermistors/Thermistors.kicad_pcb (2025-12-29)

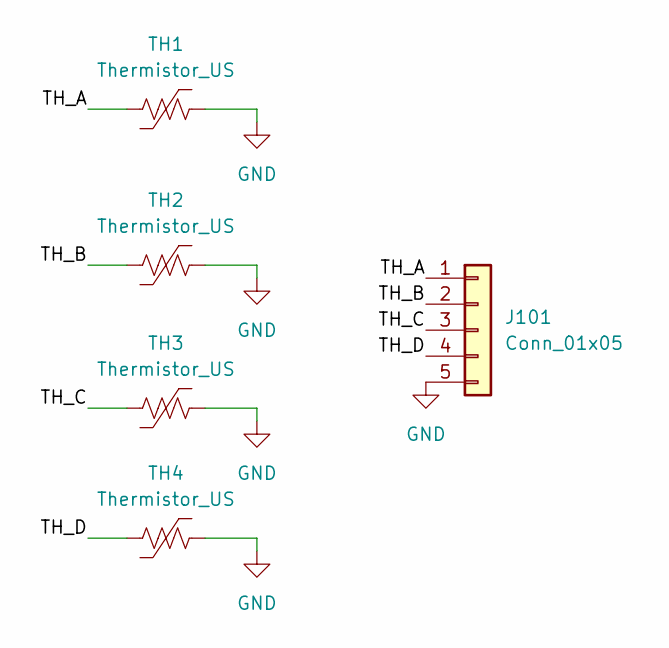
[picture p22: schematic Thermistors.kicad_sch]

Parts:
J101: Conn_01x05; FPC_5pin
TH1, TH2, TH3, TH4: Thermistor_US; R_0402_1005Metric

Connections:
/TH_A: J101.1, TH1.1
/TH_B: J101.2, TH2.1
/TH_C: J101.3, TH3.1
/TH_D: J101.4, TH4.1
GND: J101.5, TH1.2, TH2.2, TH3.2, TH4.2

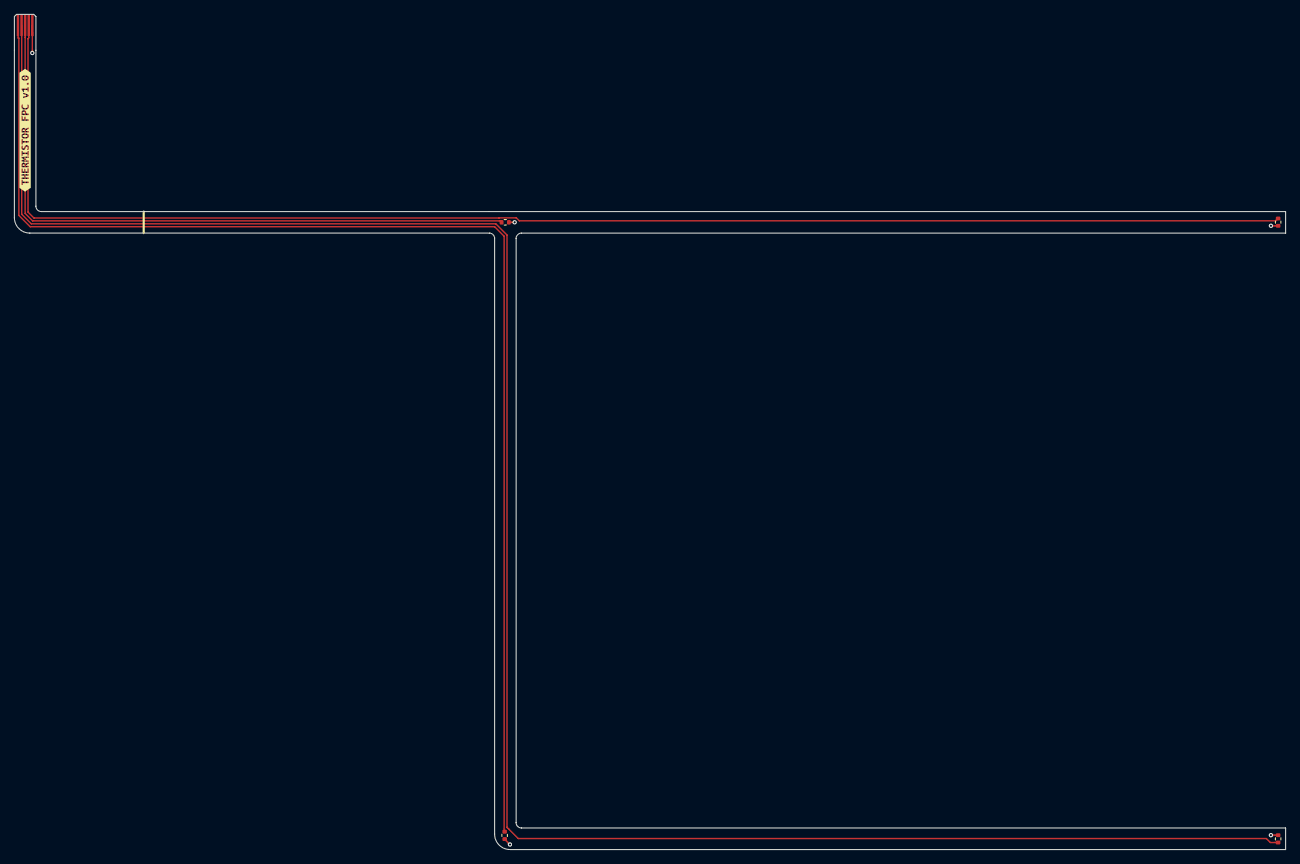
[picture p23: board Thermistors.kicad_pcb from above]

Board: 2 copper layers, 177.1 x 116.4 mm, 6 parts (0 on the bottom side), 5 nets.

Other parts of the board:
kibuzzard-6936739F: G***; kibuzzard-6936739F

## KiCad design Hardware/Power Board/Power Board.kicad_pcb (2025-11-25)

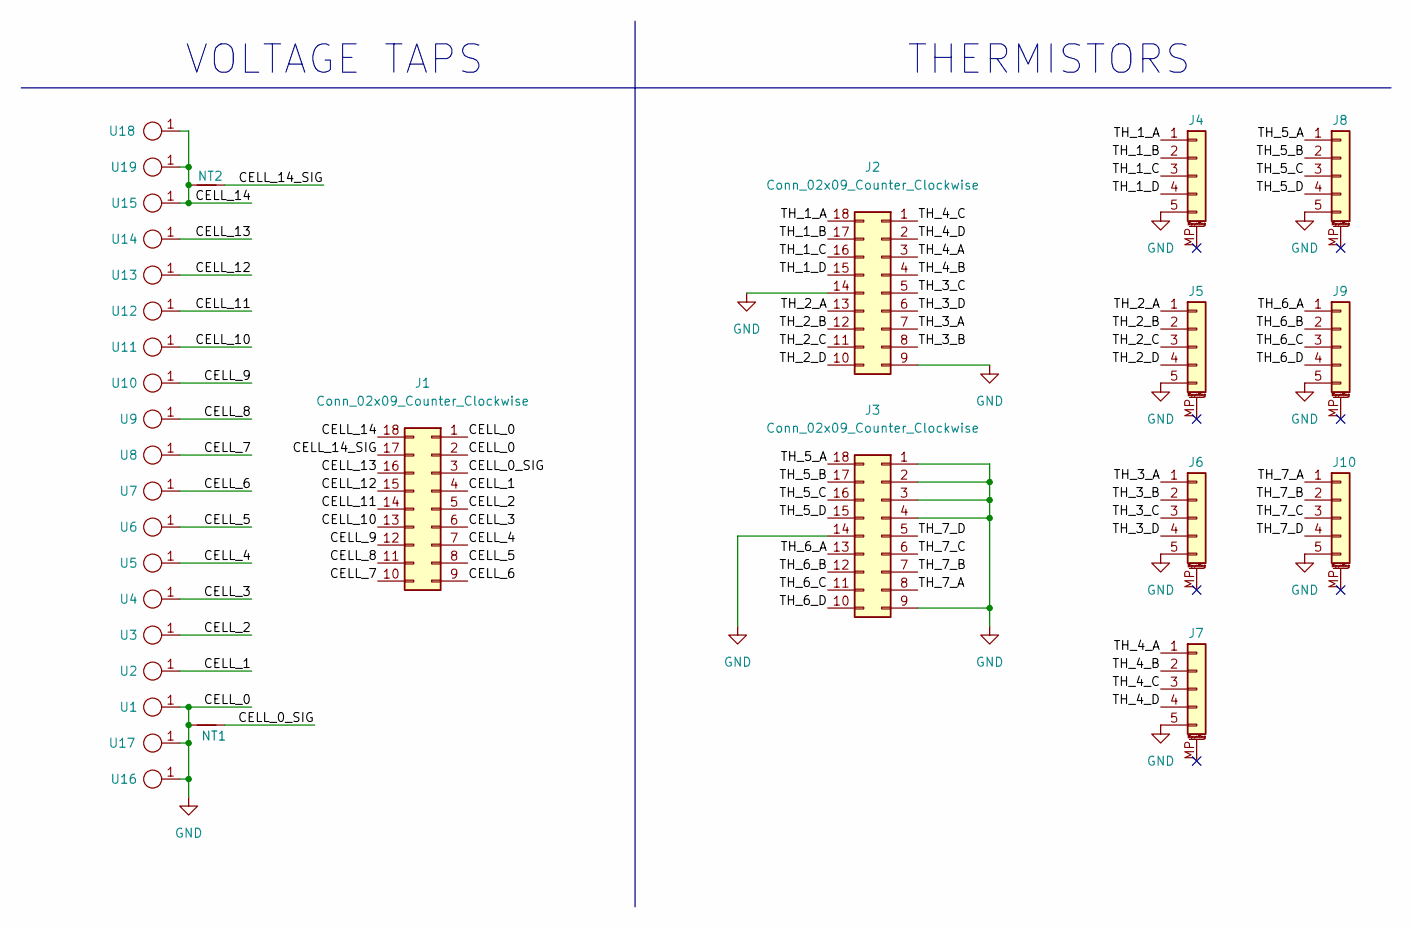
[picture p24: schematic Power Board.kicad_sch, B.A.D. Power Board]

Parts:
J1, J2, J3: Conn_02x09_Counter_Clockwise; PinHeader_2x09_P2.54mm_Vertical
J4, J5, J6, J7, J8, J9, J10: Conn_01x05_MountingPin; TE_0-1734839-5_1x05-1MP_P0.5mm_Horizontal
NT1, NT2: NetTie_2; NetTie-2_SMD_Pad0.5mm
U1, U2, U3, U4, U5, U6, U7, U8, U9, U10, U11, U12, U13, U14, U15: BatteryTab
U16, U17, U18, U19: 7461098

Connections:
/CELL_0_SIG: J1.3, NT1.2
/CELL_1: J1.4, U2.1
/CELL_2: J1.5, U3.1
/CELL_3: J1.6, U4.1
/CELL_4: J1.7, U5.1
/CELL_5: J1.8, U6.1
/CELL_6: J1.9, U7.1
/CELL_7: J1.10, U8.1
/CELL_8: J1.11, U9.1
/CELL_9: J1.12, U10.1
/CELL_10: J1.13, U11.1
/CELL_11: J1.14, U12.1
/CELL_12: J1.15, U13.1
/CELL_13: J1.16, U14.1
/CELL_14: J1.18, NT2.2, U15.1, U18.1, U19.1
/CELL_14_SIG: J1.17, NT2.1
/TH_1_A: J2.18, J4.1
/TH_1_B: J2.17, J4.2
/TH_1_C: J2.16, J4.3
/TH_1_D: J2.15, J4.4
/TH_2_A: J2.13, J5.1
/TH_2_B: J2.12, J5.2
/TH_2_C: J2.11, J5.3
/TH_2_D: J2.10, J5.4
/TH_3_A: J2.7, J6.1
/TH_3_B: J2.8, J6.2
/TH_3_C: J2.5, J6.3
/TH_3_D: J2.6, J6.4
/TH_4_A: J2.3, J7.1
/TH_4_B: J2.4, J7.2
/TH_4_C: J2.1, J7.3
/TH_4_D: J2.2, J7.4
/TH_5_A: J3.18, J8.1
/TH_5_B: J3.17, J8.2
/TH_5_C: J3.16, J8.3
/TH_5_D: J3.15, J8.4
/TH_6_A: J3.13, J9.1
/TH_6_B: J3.12, J9.2
/TH_6_C: J3.11, J9.3
/TH_6_D: J3.10, J9.4
/TH_7_A: J3.8, J10.1
/TH_7_B: J3.7, J10.2
/TH_7_C: J3.6, J10.3
/TH_7_D: J3.5, J10.4
GND: J1.1, J1.2, J2.9, J2.14, J3.1, J3.2, J3.3, J3.4, J3.9, J3.14, J4.5, J5.5, J6.5, J7.5, J8.5, J9.5, J10.5, NT1.1, U1.1, U16.1, U17.1

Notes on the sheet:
THERMISTORS
VOLTAGE TAPS

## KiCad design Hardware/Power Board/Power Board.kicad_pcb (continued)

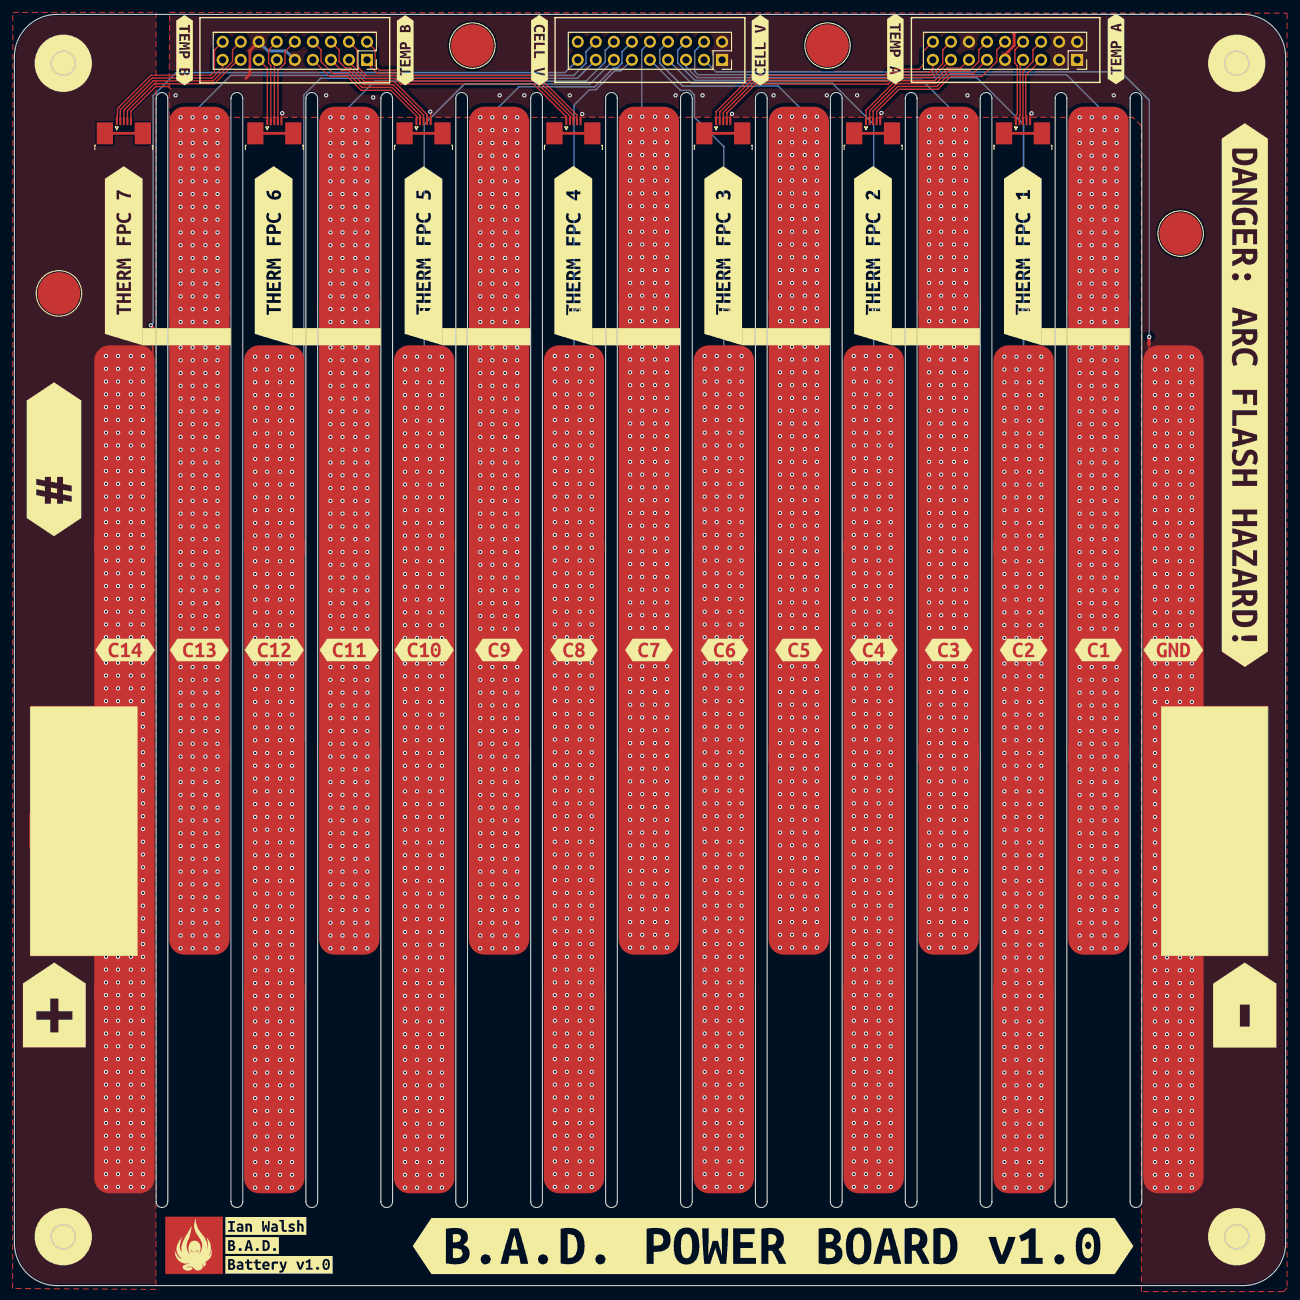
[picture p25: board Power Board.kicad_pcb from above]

Board: 4 copper layers, 179.0 x 179.0 mm, 67 parts (0 on the bottom side), 45 nets.

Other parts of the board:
kibuzzard-68FE6C25: G***; kibuzzard-68FE6C25
kibuzzard-68FE8BAD: G***; kibuzzard-68FE8BAD
kibuzzard-68FE8C3A: G***; kibuzzard-68FE8C3A
kibuzzard-68FE8C6B: G***; kibuzzard-68FE8C6B
kibuzzard-68FE8C6F: G***; kibuzzard-68FE8C6F
kibuzzard-68FE8C7B: G***; kibuzzard-68FE8C7B
kibuzzard-68FE8C8C: G***; kibuzzard-68FE8C8C
kibuzzard-68FE8C9C: G***; kibuzzard-68FE8C9C
kibuzzard-68FE8C40: G***; kibuzzard-68FE8C40
kibuzzard-68FE8C46: G***; kibuzzard-68FE8C46
kibuzzard-68FE8C51: G***; kibuzzard-68FE8C51
kibuzzard-68FE8C58: G***; kibuzzard-68FE8C58
kibuzzard-68FE8C80: G***; kibuzzard-68FE8C80
kibuzzard-68FE8C86: G***; kibuzzard-68FE8C86
kibuzzard-68FE8C91: G***; kibuzzard-68FE8C91
kibuzzard-68FE8C96: G***; kibuzzard-68FE8C96
kibuzzard-68FE971D: G***; kibuzzard-68FE971D
kibuzzard-68FE972D: G***; kibuzzard-68FE972D
kibuzzard-68FE9722: G***; kibuzzard-68FE9722
kibuzzard-68FE9727: G***; kibuzzard-68FE9727
kibuzzard-68FE9731: G***; kibuzzard-68FE9731
kibuzzard-68FE9739: G***; kibuzzard-68FE9739
kibuzzard-69080D2C, kibuzzard-69080D2C#2: G***; kibuzzard-69080D2C
kibuzzard-69080D5F: G***; kibuzzard-69080D5F
kibuzzard-69080D67: G***; kibuzzard-69080D67
kibuzzard-69080DC3: G***; kibuzzard-69080DC3
kibuzzard-69080DCA: G***; kibuzzard-69080DCA
kibuzzard-69081DDA: G***; kibuzzard-69081DDA
kibuzzard-69081DE1: G***; kibuzzard-69081DE1
kibuzzard-690804B6: G***; kibuzzard-690804B6
kibuzzard-690816F8: G***; kibuzzard-690816F8
kibuzzard-6908043A: G***; kibuzzard-6908043A
kibuzzard-69080430: G***; kibuzzard-69080430
kibuzzard-69080435: G***; kibuzzard-69080435
kibuzzard-69080668: G***; kibuzzard-69080668

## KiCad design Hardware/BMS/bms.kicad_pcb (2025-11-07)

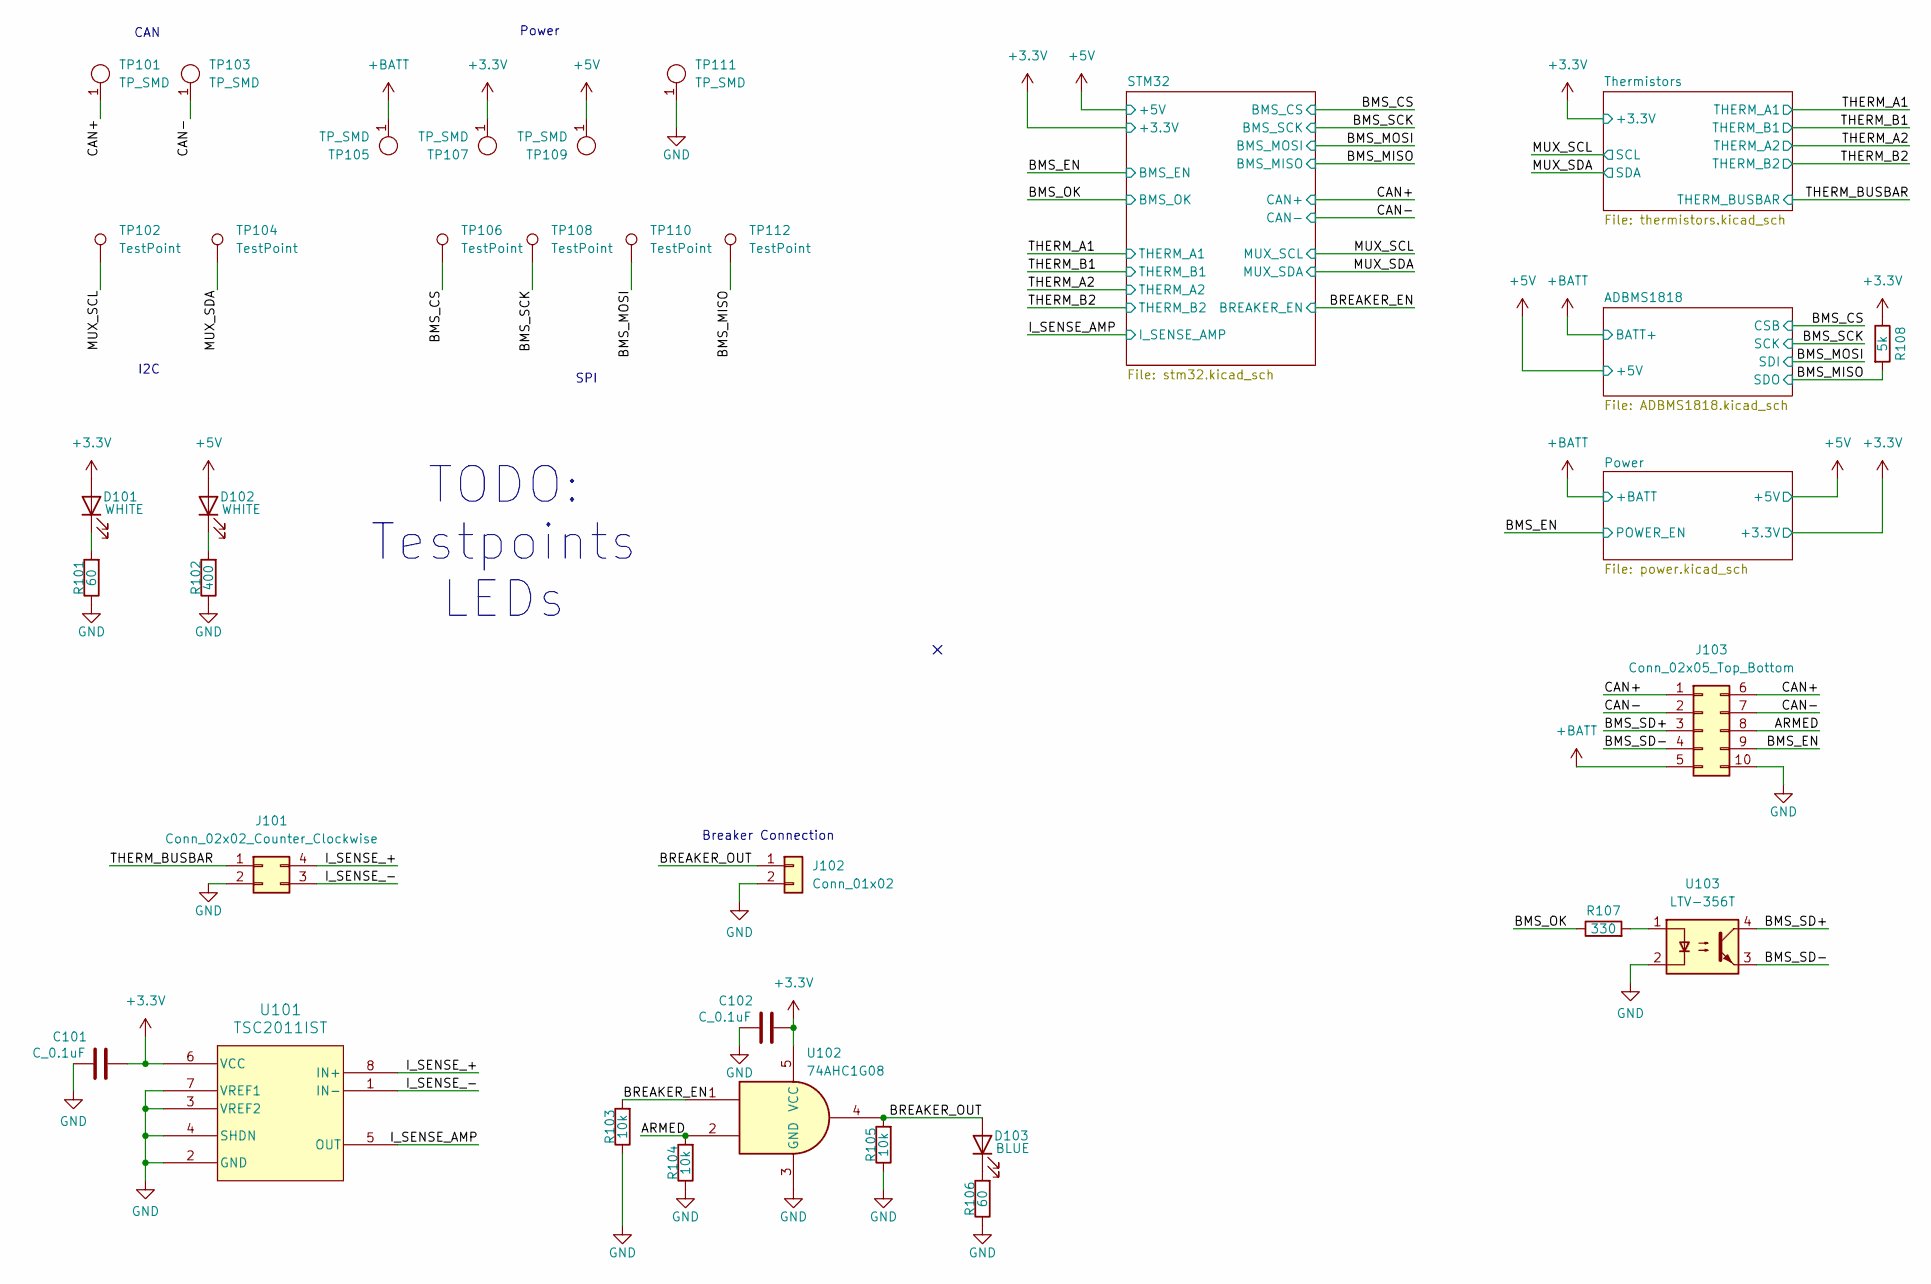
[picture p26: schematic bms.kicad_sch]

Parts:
C101, C102: C_0.1uF; C_0603_1608Metric; MPN 478-3352-1-ND
D101, D102: WHITE; LED_0805_2012Metric
D103: BLUE; LED_0805_2012Metric
J101: Conn_02x02_Counter_Clockwise; Molex_Micro-Fit_3.0_43045-0400_2x02_P3.00mm_Horizontal
J102: Conn_01x02; Molex_Micro-Fit_3.0_43650-0200_1x02_P3.00mm_Horizontal
J103: Conn_02x05_Top_Bottom; Molex_Micro-Fit_3.0_43045-1000_2x05_P3.00mm_Horizontal
R101, R106: 60; R_0603_1608Metric
R102: 400; R_0603_1608Metric
R103, R104, R105: 10k; R_0603_1608Metric
R107: 330; R_0603_1608Metric; MPN RMCF0603FT1K00
R108: 5k; R_0603_1608Metric; MPN RMCF0603FT1K00
TP101, TP103, TP105, TP107, TP109, TP111: TP_SMD; TestPoint_Keystone_5019_Miniature; MPN 5019
TP102, TP104, TP106, TP108, TP110, TP112: TestPoint; TestPoint_Pad_1.0x1.0mm
U101: TSC2011IST; SO_011IST_STM-M
U102: 74AHC1G08; SOT-23-5
U103: LTV-356T; SO-4_4.4x3.6mm_P2.54mm

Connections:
+3.3V: C101.2, C102.2, D101.2 (A), R108.1, TP107.1, U101.6 (VCC), U102.5 (VCC); also elsewhere on the board
+5V: D102.2 (A), TP109.1; also elsewhere on the board
/ARMED: J103.8, R104.2, U102.2
/BMS_CS: TP106.1; also elsewhere on the board
/BMS_EN: J103.9; also elsewhere on the board
/BMS_MISO: R108.2, TP112.1; also elsewhere on the board
/BMS_MOSI: TP110.1; also elsewhere on the board
/BMS_OK: R107.1; also elsewhere on the board
/BMS_SCK: TP108.1; also elsewhere on the board
/BMS_SD+: J103.3, U103.4
/BMS_SD-: J103.4, U103.3
/BREAKER_EN: R103.2, U102.1; also elsewhere on the board
/BREAKER_OUT: D103.2 (A), J102.1, R105.2, U102.4
/CAN+: J103.1, J103.6, TP101.1; also elsewhere on the board
/CAN-: J103.2, J103.7, TP103.1; also elsewhere on the board
/I_SENSE_+: J101.4, U101.8 (IN+)
/I_SENSE_-: J101.3, U101.1 (IN-)
/I_SENSE_AMP: U101.5 (OUT); also elsewhere on the board
/MUX_SCL: TP102.1; also elsewhere on the board
/MUX_SDA: TP104.1; also elsewhere on the board
/THERM_BUSBAR: J101.1; also elsewhere on the board
GND: C101.1, C102.1, J101.2, J102.2, J103.10, R101.1, R102.1, R103.1, R104.1, R105.1, R106.1, TP111.1, U101.2 (GND), U101.3 (VREF2), U101.4 (SHDN), U101.7 (VREF1), U102.3 (GND), U103.2; also elsewhere on the board
unnamed: D101.1 (K), R101.2
unnamed: D102.1 (K), R102.2
unnamed: D103.1 (K), R106.2
unnamed: R107.2, U103.1

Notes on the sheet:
I2C
CAN
TODO: Testpoints LEDs
SPI
Breaker Connection
Power

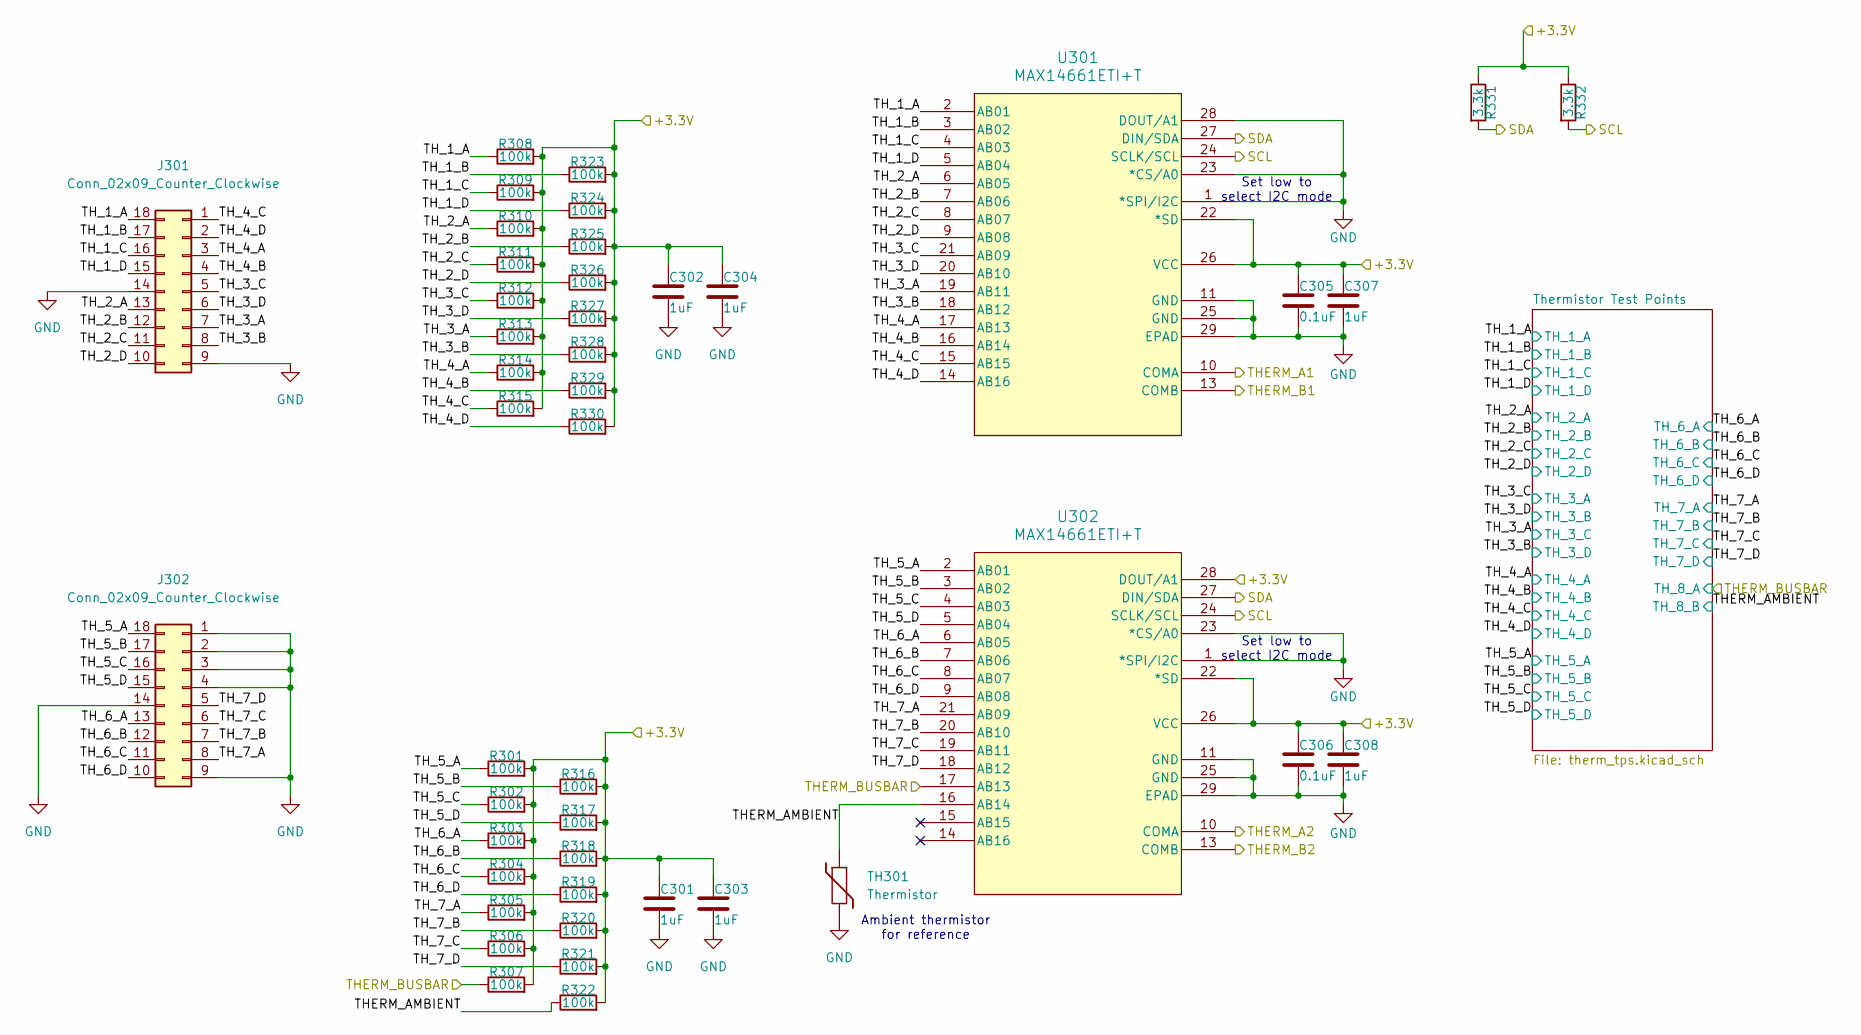
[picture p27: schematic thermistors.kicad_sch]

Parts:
C301, C302, C303, C304, C307, C308: 1uF; C_0603_1608Metric
C305, C306: 0.1uF; C_0603_1608Metric
J301, J302: Conn_02x09_Counter_Clockwise; PinSocket_2x09_P2.54mm_Vertical
R301, R302, R303, R304, R305, R306, R307, R308, R309, R310, R311, R312, R313, R314, R315, R316, R317, R318, R319, R320, R321, R322, R323, R324, R325, R326, R327, R328, R329, R330: 100k; R_0603_1608Metric
R331, R332: 3.3k; R_0603_1608Metric
TH301: Thermistor; R_0603_1608Metric
U301, U302: MAX14661ETI+T; 21-0139I_T2844-1_MXM

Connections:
+3.3V: C301.1, C302.1, C303.1, C304.1, C305.1, C306.1, C307.1, C308.1, R301.2, R302.2, R303.2, R304.2, R305.2, R306.2, R307.2, R308.2, R309.2, R310.2, R311.2, R312.2, R313.2, R314.2, R315.2, R316.2, R317.2, R318.2, R319.2, R320.2, R321.2, R322.2, R323.2, R324.2, R325.2, R326.2, R327.2, R328.2, R329.2, R330.2, R331.1, R332.1, U301.22 (*SD), U301.26 (VCC), U302.22 (*SD), U302.26 (VCC), U302.28 (DOUT/A1); also elsewhere on the board
/MUX_SCL: R332.2, U301.24 (SCLK/SCL), U302.24 (SCLK/SCL); also elsewhere on the board
/MUX_SDA: R331.2, U301.27 (DIN/SDA), U302.27 (DIN/SDA); also elsewhere on the board
/THERM_A1: U301.10 (COMA); also elsewhere on the board
/THERM_A2: U302.10 (COMA); also elsewhere on the board
/THERM_B1: U301.13 (COMB); also elsewhere on the board
/THERM_B2: U302.13 (COMB); also elsewhere on the board
/THERM_BUSBAR: R307.1, U302.17 (AB13); also elsewhere on the board
/Thermistors/THERM_AMBIENT: R322.1, TH301.1, U302.16 (AB14); also elsewhere on the board
/Thermistors/TH_1_A: J301.18, R308.1, U301.2 (AB01); also elsewhere on the board
/Thermistors/TH_1_B: J301.17, R323.1, U301.3 (AB02); also elsewhere on the board
/Thermistors/TH_1_C: J301.16, R309.1, U301.4 (AB03); also elsewhere on the board
/Thermistors/TH_1_D: J301.15, R324.1, U301.5 (AB04); also elsewhere on the board
/Thermistors/TH_2_A: J301.13, R310.1, U301.6 (AB05); also elsewhere on the board
/Thermistors/TH_2_B: J301.12, R325.1, U301.7 (AB06); also elsewhere on the board
/Thermistors/TH_2_C: J301.11, R311.1, U301.8 (AB07); also elsewhere on the board
/Thermistors/TH_2_D: J301.10, R326.1, U301.9 (AB08); also elsewhere on the board
/Thermistors/TH_3_A: J301.7, R313.1, U301.19 (AB11); also elsewhere on the board
/Thermistors/TH_3_B: J301.8, R328.1, U301.18 (AB12); also elsewhere on the board
/Thermistors/TH_3_C: J301.5, R312.1, U301.21 (AB09); also elsewhere on the board
/Thermistors/TH_3_D: J301.6, R327.1, U301.20 (AB10); also elsewhere on the board
/Thermistors/TH_4_A: J301.3, R314.1, U301.17 (AB13); also elsewhere on the board
/Thermistors/TH_4_B: J301.4, R329.1, U301.16 (AB14); also elsewhere on the board
/Thermistors/TH_4_C: J301.1, R315.1, U301.15 (AB15); also elsewhere on the board
/Thermistors/TH_4_D: J301.2, R330.1, U301.14 (AB16); also elsewhere on the board
/Thermistors/TH_5_A: J302.18, R301.1, U302.2 (AB01); also elsewhere on the board
/Thermistors/TH_5_B: J302.17, R316.1, U302.3 (AB02); also elsewhere on the board
/Thermistors/TH_5_C: J302.16, R302.1, U302.4 (AB03); also elsewhere on the board
/Thermistors/TH_5_D: J302.15, R317.1, U302.5 (AB04); also elsewhere on the board
/Thermistors/TH_6_A: J302.13, R303.1, U302.6 (AB05); also elsewhere on the board
/Thermistors/TH_6_B: J302.12, R318.1, U302.7 (AB06); also elsewhere on the board
/Thermistors/TH_6_C: J302.11, R304.1, U302.8 (AB07); also elsewhere on the board
/Thermistors/TH_6_D: J302.10, R319.1, U302.9 (AB08); also elsewhere on the board
GND: C301.2, C302.2, C303.2, C304.2, C305.2, C306.2, C307.2, C308.2, J301.9, J301.14, J302.1, J302.2, J302.3, J302.4, J302.9, J302.14, TH301.2, U301.1 (*SPI/I2C), U301.11 (GND), U301.23 (*CS/A0), U301.25 (GND), U301.28 (DOUT/A1), U301.29 (EPAD), U302.1 (*SPI/I2C), U302.11 (GND), U302.23 (*CS/A0), U302.25 (GND), U302.29 (EPAD); also elsewhere on the board

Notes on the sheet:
Set low to select I2C mode
Ambient thermistor for reference


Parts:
C501, C502: 1uF; C_0603_1608Metric
J501: Conn_02x09_Counter_Clockwise; PinSocket_2x09_P2.54mm_Vertical
R501: 20k; R_0603_1608Metric; MPN RMCF0603FT1K00
R502: 100; R_0603_1608Metric; MPN RMCF0603FT1K00
U501: ADBMS1818; LQFP-64-1EP_12x12_P0.5

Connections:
+5V: U501.48 (VREG); also elsewhere on the board
/ADBMS1818/C1: J501.4, U501.36 (C1); also elsewhere on the board
/ADBMS1818/C2: J501.5, U501.34 (C2); also elsewhere on the board
/ADBMS1818/C3: J501.6, U501.32 (C3); also elsewhere on the board
/ADBMS1818/C4: J501.7, U501.30 (C4); also elsewhere on the board
/ADBMS1818/C5: J501.8, U501.28 (C5); also elsewhere on the board
/ADBMS1818/C6: J501.9, U501.26 (C6); also elsewhere on the board
/ADBMS1818/C7: J501.10, U501.24 (C7); also elsewhere on the board
/ADBMS1818/C8: J501.11, U501.22 (C8); also elsewhere on the board
/ADBMS1818/C9: J501.12, U501.20 (C9); also elsewhere on the board
/ADBMS1818/C10: J501.13, U501.18 (C10); also elsewhere on the board
/ADBMS1818/C11: J501.14, U501.16 (C11); also elsewhere on the board
/ADBMS1818/C12: J501.15, U501.14 (C12); also elsewhere on the board
/ADBMS1818/C13: J501.16, U501.12 (C13); also elsewhere on the board
/ADBMS1818/C14: U501.2 (C18), U501.4 (C17), U501.6 (C16), U501.8 (C15), U501.10 (C14); also elsewhere on the board
/ADBMS1818/CELL14: J501.17; also elsewhere on the board
/ADBMS1818/S1: U501.37 (S1); also elsewhere on the board
/ADBMS1818/S2: U501.35 (S2); also elsewhere on the board
/ADBMS1818/S3: U501.33 (S3); also elsewhere on the board
/ADBMS1818/S4: U501.31 (S4); also elsewhere on the board
/ADBMS1818/S5: U501.29 (S5); also elsewhere on the board
/ADBMS1818/S6: U501.27 (S6); also elsewhere on the board
/ADBMS1818/S7: U501.25 (S7); also elsewhere on the board
/ADBMS1818/S8: U501.23 (S8); also elsewhere on the board
/ADBMS1818/S9: U501.21 (S9); also elsewhere on the board
/ADBMS1818/S10: U501.19 (S10); also elsewhere on the board
/ADBMS1818/S11: U501.17 (S11); also elsewhere on the board
/ADBMS1818/S12: U501.15 (S12); also elsewhere on the board
/ADBMS1818/S13: U501.13 (S13); also elsewhere on the board
/ADBMS1818/S14: U501.11 (S14); also elsewhere on the board
/BMS_CS: U501.61 (CSB/IMA); also elsewhere on the board
/BMS_MISO: U501.54 (SDO); also elsewhere on the board
/BMS_MOSI: U501.53 (SDI); also elsewhere on the board
/BMS_SCK: U501.62 (SCK/IPA); also elsewhere on the board
GND: C501.2, C502.2, J501.1, J501.2, J501.3, R501.1, U501.38 (C0), U501.52 (DTEN), U501.55 (ISOMD), U501.59 (V-), U501.60 (V-), U501.EPAD1 (V-); also elsewhere on the board
unnamed: R501.2, U501.57 (IBIAS), U501.58 (ICMP)
unnamed: R502.1, U501.63 (IMB)
unnamed: R502.2, U501.64 (IPB)
unnamed: C502.1, U501.51 (VREF1)
unnamed: C501.1, U501.50 (VREF2)

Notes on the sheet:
100ohm termination
pg. 13 To use isoSPI
ISOMD to GND for SPI
isoSPI Bias current set for SPI
To Voltage Filtering Hierarchical Sheet


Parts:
C601, C603, C610, C612, C619: 2.2uF; C_0603_1608Metric
C602, C605, C611, C614: 100pf; C_0603_1608Metric
C604, C613: 4.7pf; C_0603_1608Metric
C606, C607, C608, C609, C615, C616, C617, C618: 47uF; C_1206_3216Metric
D601: DZ2S082X0L; D_SOD-523
L601, L602: 22uH; L_12x12mm_H4.5mm
Q601: SQ2337ES; SOT-23
R601, R604: 10k; R_0603_1608Metric
R602, R607: 25.5k; R_0603_1608Metric
R603, R605, R608: 1M; R_0603_1608Metric
R606: 191k; R_0603_1608Metric
R609: 324k; R_0603_1608Metric
R610: 100k; R_0603_1608Metric
U601, U602: SOP65P640X120-17N

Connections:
+3.3V: C613.1, C615.1, C616.1, C617.1, C618.1, R608.1, U602.12 (Vout); also elsewhere on the board
+5V: C604.1, C606.1, C607.1, C608.1, C609.1, R605.1, U601.12 (Vout); also elsewhere on the board
/BMS_EN: R604.2; also elsewhere on the board
GND: C601.2, C602.2, C603.2, C606.2, C607.2, C608.2, C609.2, C610.2, C611.2, C612.2, C615.2, C616.2, C617.2, C618.2, C619.2, R601.2, R602.2, R606.2, R607.2, R609.2, U601.7 (SYNC/MODE), U601.21 (GND), U602.7 (SYNC/MODE), U602.21 (GND); also elsewhere on the board
unnamed: C605.1, U601.18 (BST)
unnamed: C604.2, R605.2, R606.1, U601.11 (FB)
unnamed: L601.2, U601.14 (IND)
unnamed: C603.1, U601.16 (INT_Vcc)
unnamed: R602.1, U601.8 (RT)
unnamed: C605.2, L601.1, U601.20 (SW)
unnamed: C602.1, U601.10 (TR/SS)
unnamed: C614.1, U602.18 (BST)
unnamed: C613.2, R608.2, R609.1, U602.11 (FB)
unnamed: L602.2, U602.14 (IND)
unnamed: C612.1, U602.16 (INT_Vcc)
unnamed: R607.1, U602.8 (RT)
unnamed: C614.2, L602.1, U602.20 (SW)
unnamed: C611.1, U602.10 (TR/SS)

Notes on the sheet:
3.3V Buck Converter
ADBMS Datasheet pg71
POWER-ON CIRCUIT
5V Buck Converter
POWER


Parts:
C401, C402: C_8pF; C_0603_1608Metric; MPN 1276-6717-1-ND
C403, C404, C405: C_0.1uF; C_0603_1608Metric; MPN 478-3352-1-ND
C406, C408, C409, C411: 100nF; C_0603_1608Metric; MPN 1276-6717-1-ND
C407, C412: C_100nF; C_0603_1608Metric; MPN 1276-6717-1-ND
C410, C414: 1uF; C_0603_1608Metric; MPN 1276-1052-1-ND
C413: 4.7uF; C_0805_2012Metric; MPN 1276-1052-1-ND
C415: 10uF; C_0805_2012Metric; MPN 1276-1052-1-ND
D401: WHITE; LED_0805_2012Metric
J401: Conn_01x04_Socket; PinSocket_1x04_P2.54mm_Vertical
J402: USB_C_Receptacle_USB2.0_16P; USB_C_Receptacle_G-Switch_GT-USB-7051x
Q401: 2N7002E; SOT-23
R401, R402: 120; R_0603_1608Metric; MPN 667-ERJ-6ENF1200V
R403: 10k; R_0805_OEM; MPN CRS0805-FX-1002ELFCT-ND
R404: 100; R_0805_OEM; MPN CRS0805-FX-1002ELFCT-ND
R405, R406, R407: 5.1k; R_0603_1608Metric; MPN RMCF0603FT1K00
R408: 400; R_0603_1608Metric
SW401: SW_SPDT; SW_SPDT_Shouhan_MSK12C02
SW402: SW_MEC_5G; SW_MEC_5GSH9
U401: STM32G473CCTx; LQFP-48_7x7mm_P0.5mm
U402: TCAN1042VDRQ1; D0008A_M
U403: USBLC6-2SC6; SOT-23-6
Y401: 48 MHZ; Crystal_SMD_FA238; MPN 7M48072002

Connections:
+3.3V: C404.1, C406.1, C408.1, C409.1, C410.1, C411.1, C413.1, C414.1, C415.1, SW401.1 (A), U401.1 (VBAT), U401.20 (VREF+), U401.21 (VDDA), U401.24 (VDD), U401.36 (VDD), U401.48 (VDD), U402.5 (VIO); also elsewhere on the board
+5V: C403.1, J401.1, U402.3 (VCC), U403.5 (VBUS); also elsewhere on the board
/BMS_CS: U401.12 (PA4); also elsewhere on the board
/BMS_EN: Q401.2 (S); also elsewhere on the board
/BMS_MISO: U401.14 (PA6); also elsewhere on the board
/BMS_MOSI: U401.15 (PA7); also elsewhere on the board
/BMS_OK: U401.39 (PA15); also elsewhere on the board
/BMS_SCK: U401.13 (PA5); also elsewhere on the board
/BREAKER_EN: U401.32 (PA10); also elsewhere on the board
/CAN+: R401.2, U402.7 (CANH); also elsewhere on the board
/CAN-: R402.1, U402.6 (CANL); also elsewhere on the board
/I_SENSE_AMP: U401.16 (PB0); also elsewhere on the board
/MUX_SCL: U401.31 (PA9); also elsewhere on the board
/MUX_SDA: U401.30 (PA8); also elsewhere on the board
/STM32/ADBMS_COMS: U401.25 (PB11); also elsewhere on the board
/STM32/BMS_HEARTBEAT: U401.29 (PB15); also elsewhere on the board
/STM32/BOOT0: R403.2, U401.45 (PB8)
/STM32/CAN_COMS: U401.44 (PB7); also elsewhere on the board
/STM32/D+: U401.34 (PA12), U403.3 (I/O2)
/STM32/D-: U401.33 (PA11), U403.1 (I/O1)
/STM32/DEBUG1: U401.28 (PB14); also elsewhere on the board
/STM32/ERROR: U401.42 (PB5); also elsewhere on the board
/STM32/MUX1_COMS: U401.46 (PB9); also elsewhere on the board
/STM32/MUX2_COMS: U401.22 (PB10); also elsewhere on the board
/STM32/OT: U401.40 (PB3); also elsewhere on the board
/STM32/OV: U401.17 (PB1); also elsewhere on the board
/STM32/RESET: R404.1, U401.7 (PG10)
/STM32/RXCAN: U401.26 (PB12), U402.4 (RXD)
/STM32/SWCLK: J401.2, U401.38 (PA14)
/STM32/SWDIO: J401.3, U401.37 (PA13)
/STM32/TXCAN: U401.27 (PB13), U402.1 (TXD)
/STM32/USB_C_COMS: U401.43 (PB6); also elsewhere on the board
/STM32/UT: U401.41 (PB4); also elsewhere on the board
/STM32/UV: U401.18 (PB2); also elsewhere on the board
/THERM_A1: U401.8 (PA0); also elsewhere on the board
/THERM_A2: U401.9 (PA1); also elsewhere on the board
/THERM_B1: U401.10 (PA2); also elsewhere on the board
/THERM_B2: U401.11 (PA3); also elsewhere on the board
GND: C401.2, C402.1, C403.2, C404.2, C405.2, C406.2, C407.1, C408.2, C409.2, C410.2, C411.2, C412.1, C413.2, C414.2, C415.2, J401.4, J402.A1 (GND), J402.A12 (GND), J402.B1 (GND), J402.B12 (GND), J402.S1 (SHIELD), Q401.3 (D), R405.1, R406.1, R407.2, R408.1, SW401.3 (C), SW402.1 (A), SW402.2 (A), U401.19 (VSSA), U401.23 (VSS), U401.35 (VSS), U401.47 (VSS), U402.2 (GND), U402.8 (STB), U403.2 (GND), Y401.2, Y401.4; also elsewhere on the board
unnamed: C405.1, R401.1, R402.2
unnamed: C412.2, R404.2, SW402.3 (B), SW402.4 (B)
unnamed: D401.2 (A), J402.A4 (VBUS), J402.A9 (VBUS), J402.B4 (VBUS), J402.B9 (VBUS), Q401.1 (G), R405.2
unnamed: D401.1 (K), R408.2
unnamed: J402.A5 (CC1), R406.2
unnamed: J402.B5 (CC2), R407.1
unnamed: J402.A6 (D+), J402.B6 (D+), U403.4 (I/O2)
unnamed: J402.A7 (D-), J402.B7 (D-), U403.6 (I/O1)
unnamed: C407.2, R403.1, SW401.2 (B)
unnamed: C401.1, U401.5 (PF0), Y401.3
unnamed: C402.2, U401.6 (PF1), Y401.1

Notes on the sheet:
I2C
PA4 - SPI1_CS PA5 - SPI1_SCK PA6 - SPI1_MISO PA7 - SPI1_MOSI
CAN TRANSCEIVER
SWD
SPI
USB (Programming)
I2C2
PB11 - FDCAN2_RX PB13 - FDCAN2_TX
Thermistor Inputs

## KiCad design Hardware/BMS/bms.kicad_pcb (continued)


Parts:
TP901, TP902, TP903, TP904, TP905, TP906, TP907, TP908, TP909, TP910, TP911, TP912, TP913, TP914, TP915, TP916, TP917, TP918, TP919, TP920, TP921, TP922, TP923, TP924, TP925, TP926, TP927, TP928, TP929, TP930: TestPoint; TestPoint_Pad_1.0x1.0mm

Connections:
/THERM_BUSBAR: TP929.1; also elsewhere on the board
/Thermistors/THERM_AMBIENT: TP930.1; also elsewhere on the board
/Thermistors/TH_1_A: TP901.1; also elsewhere on the board
/Thermistors/TH_1_B: TP908.1; also elsewhere on the board
/Thermistors/TH_1_C: TP915.1; also elsewhere on the board
/Thermistors/TH_1_D: TP922.1; also elsewhere on the board
/Thermistors/TH_2_A: TP902.1; also elsewhere on the board
/Thermistors/TH_2_B: TP909.1; also elsewhere on the board
/Thermistors/TH_2_C: TP916.1; also elsewhere on the board
/Thermistors/TH_2_D: TP923.1; also elsewhere on the board
/Thermistors/TH_3_A: TP917.1; also elsewhere on the board
/Thermistors/TH_3_B: TP924.1; also elsewhere on the board
/Thermistors/TH_3_C: TP903.1; also elsewhere on the board
/Thermistors/TH_3_D: TP910.1; also elsewhere on the board
/Thermistors/TH_4_A: TP904.1; also elsewhere on the board
/Thermistors/TH_4_B: TP911.1; also elsewhere on the board
/Thermistors/TH_4_C: TP918.1; also elsewhere on the board
/Thermistors/TH_4_D: TP925.1; also elsewhere on the board
/Thermistors/TH_5_A: TP905.1; also elsewhere on the board
/Thermistors/TH_5_B: TP912.1; also elsewhere on the board
/Thermistors/TH_5_C: TP919.1; also elsewhere on the board
/Thermistors/TH_5_D: TP926.1; also elsewhere on the board
/Thermistors/TH_6_A: TP906.1; also elsewhere on the board
/Thermistors/TH_6_B: TP913.1; also elsewhere on the board
/Thermistors/TH_6_C: TP920.1; also elsewhere on the board
/Thermistors/TH_6_D: TP927.1; also elsewhere on the board


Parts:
C201: C_10nF; C_0603_1608Metric; MPN CL10B103KB8NNNC
D201: WHITE; LED_0805_2012Metric
F201: 200mA_Fuse; Fuse_1206_3216Metric; MPN 0466.200NRHF
R201: 33; R_2512_6332Metric; MPN 352022RJT
R202: 100; R_0603_1608Metric
R203: 100; R_0603_1608Metric; MPN SG73P1JTTD100J

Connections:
/ADBMS1818/C1: C201.1, F201.1, R203.2; also elsewhere on the board
/ADBMS1818/S1: R201.2, R202.1; also elsewhere on the board
GND: C201.2; also elsewhere on the board
unnamed: D201.2 (A), F201.2, R201.1, R203.1
unnamed: D201.1 (K), R202.2

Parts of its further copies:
C701, C1001, C1201, C1301, C1401, C1501, C1601, C1701, C1801, C1901, C2001, C2101, C2201: C_10nF; C_0603_1608Metric; MPN CL10B103KB8NNNC
D701, D1001, D1201, D1301, D1401, D1501, D1601, D1701, D1801, D1901, D2001, D2101, D2201: WHITE; LED_0805_2012Metric
F701, F1001, F1201, F1301, F1401, F1501, F1601, F1701, F1801, F1901, F2001, F2101, F2201: 200mA_Fuse; Fuse_1206_3216Metric; MPN 0466.200NRHF
R701, R1001, R1201, R1301, R1401, R1501, R1601, R1701, R1801, R1901, R2001, R2101, R2201: 33; R_2512_6332Metric; MPN 352022RJT
R702, R1002, R1202, R1302, R1402, R1502, R1602, R1702, R1802, R1902, R2002, R2102, R2202: 100; R_0603_1608Metric
R703, R1003, R1203, R1303, R1403, R1503, R1603, R1703, R1803, R1903, R2003, R2103, R2203: 100; R_0603_1608Metric; MPN SG73P1JTTD100J

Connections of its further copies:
/ADBMS1818/C1: C701.2; also elsewhere on the board
/ADBMS1818/C2: C701.1, C1001.2, F701.1, R703.2; also elsewhere on the board
/ADBMS1818/C3: C1001.1, C1201.2, F1001.1, R1003.2; also elsewhere on the board
/ADBMS1818/C4: C1201.1, C1301.2, F1201.1, R1203.2; also elsewhere on the board
/ADBMS1818/C5: C1301.1, C1401.2, F1301.1, R1303.2; also elsewhere on the board
/ADBMS1818/C6: C1401.1, C1501.2, F1401.1, R1403.2; also elsewhere on the board
/ADBMS1818/C7: C1501.1, C1601.2, F1501.1, R1503.2; also elsewhere on the board
/ADBMS1818/C8: C1601.1, C1701.2, F1601.1, R1603.2; also elsewhere on the board
/ADBMS1818/C9: C1701.1, C1801.2, F1701.1, R1703.2; also elsewhere on the board
/ADBMS1818/C10: C1801.1, C1901.2, F1801.1, R1803.2; also elsewhere on the board
/ADBMS1818/C11: C1901.1, C2001.2, F1901.1, R1903.2; also elsewhere on the board
/ADBMS1818/C12: C2001.1, C2101.2, F2001.1, R2003.2; also elsewhere on the board
/ADBMS1818/C13: C2101.1, C2201.2, F2101.1, R2103.2; also elsewhere on the board
/ADBMS1818/C14: C2201.1, R2203.2; also elsewhere on the board
/ADBMS1818/CELL14: F2201.1; also elsewhere on the board
/ADBMS1818/S2: R701.2, R702.1; also elsewhere on the board
/ADBMS1818/S3: R1001.2, R1002.1; also elsewhere on the board
/ADBMS1818/S4: R1201.2, R1202.1; also elsewhere on the board
/ADBMS1818/S5: R1301.2, R1302.1; also elsewhere on the board
/ADBMS1818/S6: R1401.2, R1402.1; also elsewhere on the board
/ADBMS1818/S7: R1501.2, R1502.1; also elsewhere on the board
/ADBMS1818/S8: R1601.2, R1602.1; also elsewhere on the board
/ADBMS1818/S9: R1701.2, R1702.1; also elsewhere on the board
/ADBMS1818/S10: R1801.2, R1802.1; also elsewhere on the board
/ADBMS1818/S11: R1901.2, R1902.1; also elsewhere on the board
/ADBMS1818/S12: R2001.2, R2002.1; also elsewhere on the board
/ADBMS1818/S13: R2101.2, R2102.1; also elsewhere on the board
/ADBMS1818/S14: R2201.2, R2202.1; also elsewhere on the board
unnamed: D701.2 (A), F701.2, R701.1, R703.1
unnamed: D701.1 (K), R702.2
unnamed: D1001.2 (A), F1001.2, R1001.1, R1003.1
unnamed: D1001.1 (K), R1002.2
unnamed: D1201.2 (A), F1201.2, R1201.1, R1203.1
unnamed: D1201.1 (K), R1202.2
unnamed: D1301.2 (A), F1301.2, R1301.1, R1303.1
unnamed: D1301.1 (K), R1302.2
unnamed: D1401.2 (A), F1401.2, R1401.1, R1403.1
unnamed: D1401.1 (K), R1402.2
unnamed: D1501.2 (A), F1501.2, R1501.1, R1503.1
unnamed: D1501.1 (K), R1502.2
unnamed: D1601.2 (A), F1601.2, R1601.1, R1603.1
unnamed: D1601.1 (K), R1602.2
unnamed: D1701.2 (A), F1701.2, R1701.1, R1703.1
unnamed: D1701.1 (K), R1702.2
unnamed: D1801.2 (A), F1801.2, R1801.1, R1803.1
unnamed: D1801.1 (K), R1802.2
unnamed: D1901.2 (A), F1901.2, R1901.1, R1903.1
unnamed: D1901.1 (K), R1902.2
unnamed: D2001.2 (A), F2001.2, R2001.1, R2003.1
unnamed: D2001.1 (K), R2002.2
unnamed: D2101.2 (A), F2101.2, R2101.1, R2103.1
unnamed: D2101.1 (K), R2102.2
unnamed: D2201.2 (A), F2201.2, R2201.1, R2203.1
unnamed: D2201.1 (K), R2202.2

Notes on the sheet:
Filtering RC circuit as depicted on ADBMS1818 datasheet pg. 72
"A cell pin filter of 100 Ω and 10 nF is recommended for all applications" ADBMS1818 datasheet pg. 71
Cells: Samsung 40T 21700 https://cdn.shopify.com/s/files/1/0481/9678/0183/files/Samsung_Introduction_of_New_40T_v3.pdf?v=1612843210
Balance current [A] = (% SOC imbalance * battery capacity)/(num of hours to balance) = (0.05 * 64Ah) / (20) = 160 mA
RFilter
Discharge Resistor [ohms] = cell voltage / balancing current = 4.2 V / 160mA = 26.25 ohms
Use in order to have less cell connections - short high rails together
"Note that the antialiasing filter resistor is part of the discharge path and must be removed or reduced. Use of an RC for added cell voltage measurement filtering is permitted, but the filter resistor must remain small, typically around 10 Ω to reduce the effect on the balance current." pg. 72
However, since it limits the balancing current...
RDischarge
Balance Current V = 4.2 V R = R_{DISCHARGE} + R_{FILTER} + R_{DS_ON} = 26 Ω + 10 Ω + 4 Ω = 40 Ω I = 4.2 V / 40 Ω = 105 mA Power P = I^2 R = (105 mA)^2 * 40 Ω = 0.441 W
As long as balance current is below 200mA, everything is okay to use the internal MOSFETs of the ADBMS1818 chip for balancing. This is the calculated balance current for the 10087191NSH5 cells, trying to keep it under 200mA. The example in the ADBMS1818 datasheet uses 5% SOC imbalance being resolve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
This is a Hierarchical Sheet. That means that this is a "copy-paste" block for each block shown. (ie. As seen on "Voltage Filter")
CFilter
Voltage Sense Overcurrent Protection (Fuse) Rule: EV.8.4.4
Jumper


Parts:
TP801, TP802, TP803, TP804, TP805, TP806, TP807, TP808, TP809, TP810, TP811, TP812, TP813, TP814, TP815: TestPoint; TestPoint_Keystone_5019_Miniature

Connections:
/ADBMS1818/C1: TP803.1; also elsewhere on the board
/ADBMS1818/C2: TP805.1; also elsewhere on the board
/ADBMS1818/C3: TP807.1; also elsewhere on the board
/ADBMS1818/C4: TP809.1; also elsewhere on the board
/ADBMS1818/C5: TP811.1; also elsewhere on the board
/ADBMS1818/C6: TP813.1; also elsewhere on the board
/ADBMS1818/C7: TP802.1; also elsewhere on the board
/ADBMS1818/C8: TP804.1; also elsewhere on the board
/ADBMS1818/C9: TP806.1; also elsewhere on the board
/ADBMS1818/C10: TP808.1; also elsewhere on the board
/ADBMS1818/C11: TP810.1; also elsewhere on the board
/ADBMS1818/C12: TP812.1; also elsewhere on the board
/ADBMS1818/C13: TP814.1; also elsewhere on the board
/ADBMS1818/CELL14: TP815.1; also elsewhere on the board
GND: TP801.1; also elsewhere on the board

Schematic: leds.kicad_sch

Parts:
D1101, D1104, D1106, D1109, D1111: LED_0805_Red; LED_0805_OEM; MPN 475-1415-1-ND
D1102, D1105, D1108, D1110, D1112: LED_0805; LED_0805_OEM; MPN 475-1410-1-ND
D1103: LED_0805_Amber; LED_0805_OEM; MPN L71517CT-ND
D1107: WHITE; LED_0805_2012Metric
R1101, R1104, R1106, R1109, R1111: 300; R_0603_1608Metric; MPN 667-ERJ-6ENF1200V
R1102, R1105, R1108, R1110, R1112: 120; R_0603_1608Metric; MPN 667-ERJ-6ENF1200V
R1103, R1107: 220; R_0603_1608Metric; MPN 667-ERJ-6ENF1200V

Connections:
/STM32/ADBMS_COMS: D1110.2 (A); also elsewhere on the board
/STM32/BMS_HEARTBEAT: D1107.2 (A); also elsewhere on the board
/STM32/CAN_COMS: D1102.2 (A); also elsewhere on the board
/STM32/DEBUG1: D1103.2 (A); also elsewhere on the board
/STM32/ERROR: D1111.2 (A); also elsewhere on the board
/STM32/MUX1_COMS: D1105.2 (A); also elsewhere on the board
/STM32/MUX2_COMS: D1108.2 (A); also elsewhere on the board
/STM32/OT: D1106.2 (A); also elsewhere on the board
/STM32/OV: D1101.2 (A); also elsewhere on the board
/STM32/USB_C_COMS: D1112.2 (A); also elsewhere on the board
/STM32/UT: D1109.2 (A); also elsewhere on the board
/STM32/UV: D1104.2 (A); also elsewhere on the board
GND: R1101.2, R1102.2, R1103.2, R1104.2, R1105.2, R1106.2, R1107.2, R1108.2, R1109.2, R1110.2, R1111.2, R1112.2; also elsewhere on the board
unnamed: D1101.1 (K), R1101.1
unnamed: D1102.1 (K), R1102.1
unnamed: D1103.1 (K), R1103.1
unnamed: D1104.1 (K), R1104.1
unnamed: D1105.1 (K), R1105.1
unnamed: D1106.1 (K), R1106.1
unnamed: D1107.1 (K), R1107.1
unnamed: D1108.1 (K), R1108.1
unnamed: D1109.1 (K), R1109.1
unnamed: D1110.1 (K), R1110.1
unnamed: D1111.1 (K), R1111.1
unnamed: D1112.1 (K), R1112.1

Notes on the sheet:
Heartbeat in code

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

Board: 6 copper layers, 179.0 x 70.0 mm, 340 parts (1 on the bottom side), 181 nets.

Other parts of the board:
R301#2, R302#2, R303#2, R304#2, R305#2, R306#2, R307#2, R316#2, R317#2, R318#2, R319#2, R320#2, R321#2, R322#2: 100k; R_0603_1608Metric
TP905#2, TP906#2, TP907#2, TP912#2, TP913#2, TP914#2, TP919#2, TP920#2, TP921#2, TP926#2, TP927#2, TP928#2, TP929#2, TP930#2: TestPoint; TestPoint_Pad_1.0x1.0mm
U302#2: MAX14661ETI+T; 21-0139I_T2844-1_MXM
kibuzzard-68FE96E6: G***; kibuzzard-68FE96E6
kibuzzard-68FE9694: G***; kibuzzard-68FE9694
kibuzzard-68FE9708: G***; kibuzzard-68FE9708
kibuzzard-690BEEAD: G***; kibuzzard-690BEEAD
kibuzzard-690BEF4B: G***; kibuzzard-690BEF4B
kibuzzard-690CD8B4: G***; kibuzzard-690CD8B4
kibuzzard-690CF62F: G***; kibuzzard-690CF62F
kibuzzard-690CF63A: G***; kibuzzard-690CF63A
kibuzzard-690CF627: G***; kibuzzard-690CF627
kibuzzard-690D526F: G***; kibuzzard-690D526F

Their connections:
+3.3V: R301#2.2, R302#2.2, R303#2.2, R304#2.2, R305#2.2, R306#2.2, R307#2.2, R316#2.2, R317#2.2, R318#2.2, R319#2.2, R320#2.2, R321#2.2, R322#2.2, U302#2.22 (*SD), U302#2.26 (VCC), U302#2.28 (DOUT/A1); also elsewhere on the board
/MUX_SCL: U302#2.24 (SCLK/SCL); also elsewhere on the board
/MUX_SDA: U302#2.27 (DIN/SDA); also elsewhere on the board
/THERM_A2: U302#2.10 (COMA); also elsewhere on the board
/THERM_B2: U302#2.13 (COMB); also elsewhere on the board
/THERM_BUSBAR: R307#2.1, U302#2.17 (AB13); also elsewhere on the board
/Thermistors/THERM_AMBIENT: R322#2.1, U302#2.16 (AB14); also elsewhere on the board
/Thermistors/TH_5_A: R301#2.1, TP905#2.1, U302#2.2 (AB01); also elsewhere on the board
/Thermistors/TH_5_B: R316#2.1, TP912#2.1, U302#2.3 (AB02); also elsewhere on the board
/Thermistors/TH_5_C: R302#2.1, TP919#2.1, U302#2.4 (AB03); also elsewhere on the board
/Thermistors/TH_5_D: R317#2.1, TP926#2.1, U302#2.5 (AB04); also elsewhere on the board
/Thermistors/TH_6_A: R303#2.1, TP906#2.1, U302#2.6 (AB05); also elsewhere on the board
/Thermistors/TH_6_B: R318#2.1, TP913#2.1, U302#2.7 (AB06); also elsewhere on the board
/Thermistors/TH_6_C: R304#2.1, TP920#2.1, U302#2.8 (AB07); also elsewhere on the board
/Thermistors/TH_6_D: R319#2.1, TP927#2.1, U302#2.9 (AB08); also elsewhere on the board
GND: U302#2.1 (*SPI/I2C), U302#2.11 (GND), U302#2.23 (*CS/A0), U302#2.25 (GND), U302#2.29 (EPAD); also elsewhere on the board

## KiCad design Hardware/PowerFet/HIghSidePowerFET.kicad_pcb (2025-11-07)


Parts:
C1: 680nF; C_0603_1608Metric
C2: 0.1uF; C_0603_1608Metric
D1: WHITE; LED_0805_2012Metric
J1: Conn_01x02; Molex_Nano-Fit_105313-xx02_1x02_P2.50mm_Horizontal
JP1: SolderJumper_3_Bridged12; SolderJumper-3_P1.3mm_Bridged12_RoundedPad1.0x1.5mm
Q1, Q2, Q3, Q4, Q5, Q6, Q7, Q8: NTBLS0D8N08X
R1, R2: 100; R_0603_1608Metric
R3, R5, R7, R9, R11: 100k; R_0603_1608Metric
R4: 100; R_0805_2012Metric
R6, R8, R10, R12: 10; R_0603_1608Metric
U1: TPS4810-Q1; VSSOP-19
U2: LTV-356T; SO-4_4.4x3.6mm_P2.54mm

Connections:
/BATT+: Q1.3 (D), Q3.3 (D), Q5.3 (D), Q7.3 (D), R4.1
/CORE+: C1.2, Q2.3 (D), Q4.3 (D), Q6.3 (D), Q8.3 (D), U1.13 (SRC)
/DIODE+: Q1.2 (S), Q2.2 (S), Q3.2 (S), Q4.2 (S), Q5.2 (S), Q6.2 (S), Q7.2 (S), Q8.2 (S)
/G2: Q2.1 (G), Q4.1 (G), Q6.1 (G), Q8.1 (G), U1.11 (G2)
/GATE_PD: R6.1, R8.1, R10.1, R12.1, U1.14 (G1PD)
/GATE_PU: R5.2, R7.2, R9.2, R11.2, U1.15 (G1PU)
/INPUT: JP1.1 (A), R3.2, U1.3 (INP1), U2.3
/STM_INPUT: D1.2 (A), J1.2, U2.1
/VS: C2.2, JP1.3 (B), R4.2, U1.17 (CS-), U1.18 (CS+), U1.20 (VS), U2.4
GND: C2.1, J1.1, R1.1, R2.1, R3.1, U1.2 (INP2), U1.5 (FLT), U1.6 (GND), U1.7 (CS_SEL), U1.8 (ISCP), U1.9 (TMR), U1.10 (SCP_TEST)
unnamed: D1.1 (K), R1.2
unnamed: JP1.2 (C), U1.1 (EN/UVLO)
unnamed: Q1.1 (G), R5.1, R6.2
unnamed: Q3.1 (G), R7.1, R8.2
unnamed: Q5.1 (G), R9.1, R10.2
unnamed: Q7.1 (G), R11.1, R12.2
unnamed: R2.2, U2.2
unnamed: C1.1, U1.12 (BST)

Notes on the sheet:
Power N-FETs (Ideal Switching Diode)
Gate Driver
Isolation



Board: 2 copper layers, 58.1 x 52.4 mm, 39 parts (17 on the bottom side), 18 nets.

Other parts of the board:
kibuzzard-68F7A0AD: G***; kibuzzard-68F7A0AD
kibuzzard-68F7A0C5: G***; kibuzzard-68F7A0C5
kibuzzard-68F7A12F: G***; kibuzzard-68F7A12F
kibuzzard-68F7D5F0: G***; kibuzzard-68F7D5F0
kibuzzard-68F79DC8: G***; kibuzzard-68F79DC8
kibuzzard-6906AA9C: G***; kibuzzard-6906AA9C
kibuzzard-6906AD14: G***; kibuzzard-6906AD14
kibuzzard-6906C7DA: G***; kibuzzard-6906C7DA
kibuzzard-6906CB2D: G***; kibuzzard-6906CB2D
kibuzzard-6907FFCC: G***; kibuzzard-6907FFCC
kibuzzard-6907FFEA: G***; kibuzzard-6907FFEA
kibuzzard-690797E2: G***; kibuzzard-690797E2

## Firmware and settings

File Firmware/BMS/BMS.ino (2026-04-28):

#define HAL_FDCAN_MODULE_ENABLED
#define HAL_CORTEX_MODULE_ENABLED
#define HAL_ADC_MODULE_ENABLED
#define HAL_OPAMP_MODULE_ENABLED

#include "stm32g4xx_hal.h"
#include "stm32g4xx_hal_fdcan.h"
#include "stm32g4xx_hal_adc.h"
#include "stm32g4xx_hal_adc_ex.h"
#include "stm32g4xx_hal_opamp.h"
#include "can_api.h"
#include "can_lib.h"
#include "ADBMS181x.h"
#include "bms_hardware.h"
#include <SPI.h>
#include <Wire.h>
#include <math.h>

// #define NORTH
// #define EAST
// #define SOUTH
#define WEST

#if (defined(NORTH) && defined(EAST)) || (defined(NORTH) && defined(SOUTH)) || (defined(NORTH) && defined(WEST)) || (defined(EAST) && defined(SOUTH)) || (defined(EAST) && defined(WEST)) || (defined(SOUTH) && defined(WEST))
    #error "More than one BMS config selected"
#endif

#define LED PB9
#define TOTAL_IC 1

#define THERM_A1_PIN PA0
#define THERM_B1_PIN PA1
#define THERM_A2_PIN PA2
#define THERM_B2_PIN PA3

#define MUX_SDA_PIN PA8
#define MUX_SCL_PIN PA9

#define MUX1_ADDR 0x4C
#define MUX2_ADDR 0x4E

#define MAX14661_CMD_A 0x14
#define MAX14661_CMD_B 0x15

#define ISENSE_PIN PB0

// Isense Current reading 2x
const float ISENSE_ADC_REF_V = 3.3f;
const float ISENSE_ADC_MAX = 4095.0f;

// Might Recalibrate since this was made with 4x values
const float ISENSE_ZERO_RAW = 241.18f;

// Rough 2x gain estimate from your 4x calibration.
const float ISENSE_COUNTS_PER_AMP = 7.32f;
const float ISENSE_SIGN = 1.0f;
const int ISENSE_AVERAGE_SAMPLES = 100;
const int ISENSE_SAMPLE_DELAY_US = 50;
const float ISENSE_DEADBAND_A = 0.15f;
const float OVERCURRENT_LIMIT_A = 500.0f;
const int OVERCURRENT_TRIP_COUNT = 3;
uint8_t overcurrent_counter = 0;

cell_asic bms_ic;
FDCAN_HandleTypeDef hfdcan2;
OPAMP_HandleTypeDef hopamp2;
ADC_HandleTypeDef hadc2;

//Init all variables:
//bms_status
uint8_t bms_state = 0;
uint16_t bms_faults = 0, pack_voltage = 0, balancing_mask = 0;
int16_t pack_current = 0;

//bms_temp_metrics
uint16_t max_current_cell_temp = 0, min_current_cell_temp = 0, max_cell_temp_ever = 0, min_cell_temp_ever = 0, temp_threshold_low = 0, temp_threshold_high = 0;

//bms_voltage_metrics
uint16_t max_cell_voltage = 0, min_cell_voltage = 0, cell_voltage_threshold_high = 0, cell_voltage_threshold_low = 0, charger_target_voltage = 0;

//cell_voltages
uint16_t cell_1 = 0, cell_2 = 0, cell_3 = 0, cell_4 = 0, cell_5 = 0, cell_6 = 0, cell_7 = 0, cell_8 = 0, cell_9 = 0, cell_10 = 0, cell_11 = 0, cell_12 = 0, cell_13 = 0, cell_14 = 0;

//thermistors
uint16_t thermistor_1 = 0, thermistor_2 = 0, thermistor_3 = 0, thermistor_4 = 0, thermistor_5 = 0, thermistor_6 = 0, thermistor_7 = 0, thermistor_8 = 0, thermistor_9 = 0, thermistor_10 = 0, thermistor_11 = 0, thermistor_12 = 0, thermistor_13 = 0, thermistor_14 = 0, thermistor_15 = 0, thermistor_16 = 0, thermistor_17 = 0, thermistor_18 = 0, thermistor_19 = 0, thermistor_20 = 0, thermistor_21 = 0, thermistor_22 = 0, thermistor_23 = 0, thermistor_24 = 0, thermistor_25 = 0, thermistor_26 = 0, thermistor_27 = 0, thermistor_28 = 0, thermistor_29 = 0, thermistor_30 = 0;


enum BmsState {
  IDLE,
  FAULTED
};

enum BmsFaultBits {
  FAULT_ADBMS_COMMS    = 2,
  FAULT_MUX            = 4,
  FAULT_CELL_UNDERTEMP = 5,
  FAULT_CELL_OVERTEMP  = 6,
  FAULT_CELL_UNDERVOLT = 7,
  FAULT_CELL_OVERVOLT  = 8,
  FAULT_OVERCURRENT    = 12,
  FAULT_PEC            = 15
};

extern "C" void HAL_OPAMP_MspInit(OPAMP_HandleTypeDef *hopamp)
{
  if (hopamp->Instance == OPAMP2)
  {
    __HAL_RCC_SYSCFG_CLK_ENABLE();
    __HAL_RCC_GPIOB_CLK_ENABLE();

    GPIO_InitTypeDef GPIO_InitStruct = {0};
    GPIO_InitStruct.Pin = GPIO_PIN_0;
    GPIO_InitStruct.Mode = GPIO_MODE_ANALOG;
    GPIO_InitStruct.Pull = GPIO_NOPULL;
    HAL_GPIO_Init(GPIOB, &GPIO_InitStruct);
  }
}

const float CELL_VOLTAGE_LOW  = 2.5f; // Min value is can handle is 2.5(discharge)
const float CELL_VOLTAGE_HIGH = 4.20f; // Max value it can handle is 4.25(discharge)

//Must add the over current later aswell
const float TEMP_LOW_C  = -20.0f; // Min value it cna take is -20.0f(discharge)
const float TEMP_HIGH_C = 60.0f; // Max value it can tolerate = 55.0f(discharge)

int8_t last_pec_error = 0;
bool last_mux_error = false;

void OCTAL_Set_Clock(void) {
  __HAL_RCC_PWR_CLK_ENABLE();
  HAL_PWREx_ControlVoltageScaling(PWR_REGULATOR_VOLTAGE_SCALE1_BOOST);

  RCC->CR |= RCC_CR_HSEON;
  MODIFY_REG(RCC->CFGR, RCC_CFGR_SW, RCC_CFGR_SW_HSE);

  RCC_OscInitTypeDef RCC_OscInitStruct = {0};
  RCC_OscInitStruct.OscillatorType = RCC_OSCILLATORTYPE_HSE;
  RCC_OscInitStruct.HSEState = RCC_HSE_ON;
  RCC_OscInitStruct.PLL.PLLState = RCC_PLL_ON;
  RCC_OscInitStruct.PLL.PLLSource = RCC_PLLSOURCE_HSE;
  RCC_OscInitStruct.PLL.PLLM = RCC_PLLM_DIV4;
  RCC_OscInitStruct.PLL.PLLN = 24;
  RCC_OscInitStruct.PLL.PLLP = RCC_PLLP_DIV2;
  RCC_OscInitStruct.PLL.PLLQ = RCC_PLLQ_DIV6;
  RCC_OscInitStruct.PLL.PLLR = RCC_PLLR_DIV2;

  if (HAL_RCC_OscConfig(&RCC_OscInitStruct) != HAL_OK) {
    Error_Handler();
  }

  SET_BIT(RCC->CR, RCC_CR_PLLON);

  RCC_ClkInitTypeDef RCC_ClkInitStruct = {0};
  RCC_ClkInitStruct.ClockType = RCC_CLOCKTYPE_HCLK | RCC_CLOCKTYPE_SYSCLK
                              | RCC_CLOCKTYPE_PCLK1 | RCC_CLOCKTYPE_PCLK2;
  RCC_ClkInitStruct.SYSCLKSource = RCC_SYSCLKSOURCE_PLLCLK;
  RCC_ClkInitStruct.AHBCLKDivider = RCC_SYSCLK_DIV1;
  RCC_ClkInitStruct.APB1CLKDivider = RCC_HCLK_DIV1;
  RCC_ClkInitStruct.APB2CLKDivider = RCC_HCLK_DIV1;

  if (HAL_RCC_ClockConfig(&RCC_ClkInitStruct, FLASH_LATENCY_4) != HAL_OK) {
    Error_Handler();
  }

  SystemCoreClockUpdate();
  HAL_InitTick(TICK_INT_PRIORITY);
}

void init_bms_chip_array() {
  for (int i = 0; i < TOTAL_IC; i++)
  {
    bms_ic.isospi_reverse = false;

    bms_ic.ic_reg.cell_channels = 18;
    bms_ic.ic_reg.stat_channels = 4;
    bms_ic.ic_reg.aux_channels = 9;

    bms_ic.ic_reg.num_cv_reg = 6;
    bms_ic.ic_reg.num_gpio_reg = 4;
    bms_ic.ic_reg.num_stat_reg = 2;

    bms_ic.system_open_wire = 0;

    for (int j = 0; j < 18; j++)
    {
      bms_ic.cells.c_codes[j] = 0;
    }

    for (int j = 0; j < 6; j++)
    {
      bms_ic.cells.pec_match[j] = 0;
    }
  }

  ADBMS181x_init_cfg(1, &bms_ic);
  ADBMS181x_reset_crc_count(1, &bms_ic);
}

void initISense() {
  pinMode(ISENSE_PIN, INPUT_ANALOG);

  hopamp2.Instance = OPAMP2;
  hopamp2.Init.PowerMode = OPAMP_POWERMODE_NORMAL;
  hopamp2.Init.Mode = OPAMP_PGA_MODE;

  hopamp2.Init.NonInvertingInput = OPAMP_NONINVERTINGINPUT_IO2;
  hopamp2.Init.InternalOutput = ENABLE;

  hopamp2.Init.TimerControlledMuxmode = OPAMP_TIMERCONTROLLEDMUXMODE_DISABLE;

  hopamp2.Init.InvertingInput = OPAMP_INVERTINGINPUT_IO0;
  hopamp2.Init.InvertingInputSecondary = OPAMP_SEC_INVERTINGINPUT_PGA;
  hopamp2.Init.NonInvertingInputSecondary = OPAMP_SEC_NONINVERTINGINPUT_IO2;

  hopamp2.Init.PgaConnect = OPAMP_PGA_CONNECT_INVERTINGINPUT_NO;

  // 2x gain
  hopamp2.Init.PgaGain = OPAMP_PGA_GAIN_2_OR_MINUS_1;

  hopamp2.Init.UserTrimming = OPAMP_TRIMMING_FACTORY;
  hopamp2.Init.TrimmingValueP = 0;
  hopamp2.Init.TrimmingValueN = 0;

  if (HAL_OPAMP_Init(&hopamp2) != HAL_OK) {
    Serial.println("ERROR: OPAMP2 init failed");
  }

  if (HAL_OPAMP_Start(&hopamp2) != HAL_OK) {
    Serial.println("ERROR: OPAMP2 start failed");
  }

  __HAL_RCC_ADC12_CLK_ENABLE();

  hadc2.Instance = ADC2;

  hadc2.Init.ClockPrescaler = ADC_CLOCK_SYNC_PCLK_DIV4;
  hadc2.Init.Resolution = ADC_RESOLUTION_12B;
  hadc2.Init.DataAlign = ADC_DATAALIGN_RIGHT;
  hadc2.Init.GainCompensation = 0;
  hadc2.Init.ScanConvMode = ADC_SCAN_DISABLE;
  hadc2.Init.EOCSelection = ADC_EOC_SINGLE_CONV;
  hadc2.Init.LowPowerAutoWait = DISABLE;
  hadc2.Init.ContinuousConvMode = DISABLE;
  hadc2.Init.NbrOfConversion = 1;
  hadc2.Init.DiscontinuousConvMode = DISABLE;
  hadc2.Init.ExternalTrigConv = ADC_SOFTWARE_START;
  hadc2.Init.ExternalTrigConvEdge = ADC_EXTERNALTRIGCONVEDGE_NONE;
  hadc2.Init.DMAContinuousRequests = DISABLE;
  hadc2.Init.Overrun = ADC_OVR_DATA_PRESERVED;
  hadc2.Init.OversamplingMode = DISABLE;

  if (HAL_ADC_Init(&hadc2) != HAL_OK) {
    Serial.println("ERROR: ADC2 re-init failed");
  }

  if (HAL_ADCEx_Calibration_Start(&hadc2, ADC_SINGLE_ENDED) != HAL_OK) {
    Serial.println("ERROR: ADC2 re-calibration failed");
  }

  ADC_ChannelConfTypeDef sConfig = {0};
  sConfig.Channel = ADC_CHANNEL_VOPAMP2;
  sConfig.Rank = ADC_REGULAR_RANK_1;
  sConfig.SamplingTime = ADC_SAMPLETIME_47CYCLES_5;
  sConfig.SingleDiff = ADC_SINGLE_ENDED;
  sConfig.OffsetNumber = ADC_OFFSET_NONE;
  sConfig.Offset = 0;

  if (HAL_ADC_ConfigChannel(&hadc2, &sConfig) != HAL_OK) {
    Serial.println("ERROR: ADC2 VOPAMP2 channel config failed");
  }
}

void init_thermistors() {
  pinMode(THERM_A1_PIN, INPUT_ANALOG);
  pinMode(THERM_B1_PIN, INPUT_ANALOG);
  pinMode(THERM_A2_PIN, INPUT_ANALOG);
  pinMode(THERM_B2_PIN, INPUT_ANALOG);

  Wire.setSDA(MUX_SDA_PIN);
  Wire.setSCL(MUX_SCL_PIN);
  Wire.begin();
  Wire.setClock(100000);

  analogReadResolution(12);

  set_mux_channels(MUX1_ADDR, 0, 1);
  set_mux_channels(MUX2_ADDR, 0, 1);

  max_cell_temp_ever = thermistorEncode(0);
  min_cell_temp_ever = thermistorEncode(120);
}

bool set_mux_channels(uint8_t mux_addr, uint8_t chA, uint8_t chB) {
  if (chA > 0x10 || chB > 0x10) return false;

  Wire.beginTransmission(mux_addr);
  Wire.write(MAX14661_CMD_A);
  Wire.write(chA);
  Wire.write(chB);
  return (Wire.endTransmission() == 0);
}

float therm_raw_to_temp_c(float raw) {
  float v_out = (3.3f * raw) / 4095.0f;
  if (v_out <= 0.0f || v_out >= 3.3f) {
    return 0.0;
  }

  float temp_k = 1.0f / (
    (1.0f / 298.15f) +
    (1.0f / 4250.0f) * log(v_out / (3.3f - v_out))
  );

  return temp_k - 273.15f;
}

void set_fault_bit(uint8_t bit) {
  bms_faults |= (1U << bit);
}

bool read_cell_voltages() {
  min_cell_voltage = 5000.0f;
  max_cell_voltage = 0.0f;
  pack_voltage = 0.0f;

  wakeup_idle(1);
  ADBMS181x_adcv(MD_7KHZ_3KHZ, DCP_DISABLED, CELL_CH_ALL);
  ADBMS181x_pollAdc();

  last_pec_error = ADBMS181x_rdcv(0, 1, &bms_ic);

    for (int cell = 0; cell < 14; cell++)
    {
      double volts = bms_ic.cells.c_codes[cell] * 0.0001f;

      switch (cell)
      {
        // -------- group 0 --------
        case 0: cell_1 = can_lib_cell_voltages_0_north_cell_1_encode(volts * 1000); break;
        case 1: cell_2 = can_lib_cell_voltages_0_north_cell_2_encode(volts * 1000); break;
        case 2: cell_3 = can_lib_cell_voltages_0_north_cell_3_encode(volts * 1000); break;
        case 3: cell_4 = can_lib_cell_voltages_0_north_cell_4_encode(volts * 1000); break;
        case 4: cell_5 = can_lib_cell_voltages_0_north_cell_5_encode(volts * 1000); break;
        // -------- group 1 --------
        case 5: cell_6 = can_lib_cell_voltages_1_north_cell_6_encode(volts * 1000); break;
        case 6: cell_7 = can_lib_cell_voltages_1_north_cell_7_encode(volts * 1000); break;
        case 7: cell_8 = can_lib_cell_voltages_1_north_cell_8_encode(volts * 1000); break;
        case 8: cell_9 = can_lib_cell_voltages_1_north_cell_9_encode(volts * 1000); break;
        case 9: cell_10 = can_lib_cell_voltages_1_north_cell_10_encode(volts * 1000); break;
        // -------- group 2 --------
        case 10: cell_11 = can_lib_cell_voltages_2_north_cell_11_encode(volts * 1000); break;
        case 11: cell_12 = can_lib_cell_voltages_2_north_cell_12_encode(volts * 1000); break;
        case 12: cell_13 = can_lib_cell_voltages_2_north_cell_13_encode(volts * 1000); break;
        case 13: cell_14 = can_lib_cell_voltages_2_north_cell_14_encode(volts * 1000); break;
      }

      if (volts * 1000 < can_lib_bms_voltage_metrics_north_max_cell_voltage_decode(min_cell_voltage)) min_cell_voltage = can_lib_bms_voltage_metrics_north_max_cell_voltage_encode(volts * 1000);
      if (volts * 1000 > can_lib_bms_voltage_metrics_north_min_cell_voltage_decode(max_cell_voltage)) max_cell_voltage = can_lib_bms_voltage_metrics_north_min_cell_voltage_encode(volts * 1000);

     pack_voltage += can_lib_bms_status_north_pack_voltage_encode(volts * 1000);
   
    }

    cell_voltage_threshold_high = can_lib_bms_voltage_metrics_north_cell_voltage_threshold_high_encode(CELL_VOLTAGE_HIGH * 1000);
    cell_voltage_threshold_low = can_lib_bms_voltage_metrics_north_cell_voltage_threshold_high_encode(CELL_VOLTAGE_LOW * 1000);

    digitalWrite(PB11, last_pec_error == 0);

  return (last_pec_error == 0);
}

uint16_t thermistorEncode(float t) {
  return (uint16_t)((t + 20.0) / 140.0 * 65536.0);
}

float thermistorDecode(uint16_t t) {
  return (float)(t * 140.0 / 65536.0 - 20.0);
}

uint8_t thermistors_index = 14;
bool read_thermistors() {
  last_mux_error = false;

  float t1 = therm_raw_to_temp_c(analogRead(THERM_A1_PIN));
  float t2 = therm_raw_to_temp_c(analogRead(THERM_B1_PIN));
  float t3 = therm_raw_to_temp_c(analogRead(THERM_A2_PIN));
  float t4 = therm_raw_to_temp_c(analogRead(THERM_B2_PIN));

  thermistors_index += 2;
  if(thermistors_index == 14) {
    thermistors_index = 0;

      Serial.println(thermistorDecode(max_current_cell_temp));
  // Serial.println(thermistorDecode(min_current_cell_temp));

    min_current_cell_temp = thermistorEncode(120);
    max_current_cell_temp = thermistorEncode(-20);
  }


  if (t1 < min_current_cell_temp) min_current_cell_temp = thermistorEncode(t1);
  if (t2 < min_current_cell_temp) min_current_cell_temp = thermistorEncode(t2);
  if (t3 < min_current_cell_temp) min_current_cell_temp = thermistorEncode(t3);
  if (t4 < min_current_cell_temp) min_current_cell_temp = thermistorEncode(t4);

  if (t1 > max_current_cell_temp) max_current_cell_temp = thermistorEncode(t1);
  if (t2 > max_current_cell_temp) max_current_cell_temp = thermistorEncode(t2);
  if (t3 > max_current_cell_temp) max_current_cell_temp = thermistorEncode(t3);
  if (t4 > max_current_cell_temp) max_current_cell_temp = thermistorEncode(t4);

  bool mux1_ok = set_mux_channels(MUX1_ADDR, thermistors_index, thermistors_index + 1);
  digitalWrite(PB7, mux1_ok);
  // if(mux1_ok) {digitalToggle(PB7);}
  bool mux2_ok = set_mux_channels(MUX2_ADDR, thermistors_index, thermistors_index + 1);
  digitalWrite(PA15, mux2_ok);
  // if(mux2_ok) {digitalToggle(PA15);}

  //timer delay compensates for mux warmup
  if ((!mux1_ok || !mux2_ok) && millis() > 15000)
  {
    last_mux_error = true;
    return false;
  }

  return true;
}


float currentRollingAvg = 0.0;
#define ROLLING_AVG_PERCENT 0.90

int32_t readVOPAMP2Once()
{
  if (HAL_ADC_Start(&hadc2) != HAL_OK)
  {
    HAL_ADC_Stop(&hadc2);
    return -1;
  }

  if (HAL_ADC_PollForConversion(&hadc2, 10) != HAL_OK)
  {
    HAL_ADC_Stop(&hadc2);
    return -1;
  }

  uint16_t raw = HAL_ADC_GetValue(&hadc2);
  HAL_ADC_Stop(&hadc2);

  return raw;
}

float readVOPAMP2Average(int samples)
{
  uint32_t sum = 0;
  int good_samples = 0;

  if (!reinitADC2ForVOPAMP2())
  {
    return -1.0f;
  }

  for (int i = 0; i < samples; i++)
  {
    int32_t raw = readVOPAMP2Once();

    if (raw >= 0)
    {
      sum += raw;
      good_samples++;
    }

    delayMicroseconds(ISENSE_SAMPLE_DELAY_US);
  }

  if (good_samples == 0)
  {
    return -1.0f;
  }

  return (float)sum / (float)good_samples;
}

bool reinitADC2ForVOPAMP2()
{
  HAL_ADC_Stop(&hadc2);
  HAL_ADC_DeInit(&hadc2);

  __HAL_RCC_ADC12_CLK_ENABLE();

  hadc2.Instance = ADC2;

  hadc2.Init.ClockPrescaler = ADC_CLOCK_SYNC_PCLK_DIV4;
  hadc2.Init.Resolution = ADC_RESOLUTION_12B;
  hadc2.Init.DataAlign = ADC_DATAALIGN_RIGHT;
  hadc2.Init.GainCompensation = 0;
  hadc2.Init.ScanConvMode = ADC_SCAN_DISABLE;
  hadc2.Init.EOCSelection = ADC_EOC_SINGLE_CONV;
  hadc2.Init.LowPowerAutoWait = DISABLE;
  hadc2.Init.ContinuousConvMode = DISABLE;
  hadc2.Init.NbrOfConversion = 1;
  hadc2.Init.DiscontinuousConvMode = DISABLE;
  hadc2.Init.ExternalTrigConv = ADC_SOFTWARE_START;
  hadc2.Init.ExternalTrigConvEdge = ADC_EXTERNALTRIGCONVEDGE_NONE;
  hadc2.Init.DMAContinuousRequests = DISABLE;
  hadc2.Init.Overrun = ADC_OVR_DATA_PRESERVED;
  hadc2.Init.OversamplingMode = DISABLE;

  if (HAL_ADC_Init(&hadc2) != HAL_OK)
  {
    Serial.println("ERROR: ADC2 re-init failed");
    return false;
  }

  if (HAL_ADCEx_Calibration_Start(&hadc2, ADC_SINGLE_ENDED) != HAL_OK)
  {
    Serial.println("ERROR: ADC2 re-calibration failed");
    return false;
  }

  return configureADC2ForVOPAMP2Channel();
}

bool configureADC2ForVOPAMP2Channel()
{
  ADC_ChannelConfTypeDef sConfig = {0};
  sConfig.Channel = ADC_CHANNEL_VOPAMP2;
  sConfig.Rank = ADC_REGULAR_RANK_1;
  sConfig.SamplingTime = ADC_SAMPLETIME_47CYCLES_5;
  sConfig.SingleDiff = ADC_SINGLE_ENDED;
  sConfig.OffsetNumber = ADC_OFFSET_NONE;
  sConfig.Offset = 0;

  if (HAL_ADC_ConfigChannel(&hadc2, &sConfig) != HAL_OK)
  {
    Serial.println("ERROR: ADC2 VOPAMP2 channel config failed");
    return false;
  }

  return true;
}


void readIsense() {
  float raw = readVOPAMP2Average(50);
  // ADC_ChannelConfTypeDef sConfig = {0};
  // sConfig.Channel = ADC_CHANNEL_VOPAMP2;
  // sConfig.Rank = ADC_REGULAR_RANK_1;
  // sConfig.SamplingTime = ADC_SAMPLETIME_47CYCLES_5;
  // sConfig.SingleDiff = ADC_SINGLE_ENDED;
  // sConfig.OffsetNumber = ADC_OFFSET_NONE;
  // sConfig.Offset = 0;

  // if (HAL_ADC_ConfigChannel(&hadc2, &sConfig) != HAL_OK) {
  //   Serial.println("ERROR: ADC2 VOPAMP2 channel config failed");
  // }

  // //IIR rolling average
  // if (HAL_ADC_Start(&hadc2) != HAL_OK) {HAL_ADC_Stop(&hadc2);}
  // if (HAL_ADC_PollForConversion(&hadc2, 10) != HAL_OK){HAL_ADC_Stop(&hadc2);}
  // uint16_t raw = HAL_ADC_GetValue(&hadc2);
  // HAL_ADC_Stop(&hadc2);

  currentRollingAvg = currentRollingAvg * ROLLING_AVG_PERCENT + (float)raw * (1-ROLLING_AVG_PERCENT);



  //Calcualte current in dA
  float current_A = ((currentRollingAvg  - ISENSE_ZERO_RAW) * 3.3 / 4096.0) / ISENSE_COUNTS_PER_AMP * 1000 * 1.22;

  Serial.println(current_A);
  
  //Do overcurrent catching
  if(current_A > 5000) {overcurrent_counter++;}
  if(overcurrent_counter > 50) {set_fault_bit(FAULT_OVERCURRENT);}

  pack_current = (int16_t)current_A;
  Serial.println(pack_current);
}

void update_faults() {
  if (last_pec_error != 0)
  {
    set_fault_bit(FAULT_ADBMS_COMMS);
    set_fault_bit(FAULT_PEC);
  }

  if (last_mux_error)
  {
    set_fault_bit(FAULT_MUX);
  }

  if (can_lib_bms_voltage_metrics_north_min_cell_voltage_decode(min_cell_voltage) < CELL_VOLTAGE_LOW * 1000)
  {
    set_fault_bit(FAULT_CELL_UNDERVOLT);
  }

  if (can_lib_bms_voltage_metrics_north_max_cell_voltage_decode(max_cell_voltage) > CELL_VOLTAGE_HIGH  * 1000.0)
  {
    set_fault_bit(FAULT_CELL_OVERVOLT);
  }

  if (thermistorDecode(min_cell_temp_ever) < TEMP_LOW_C)
  {
    set_fault_bit(FAULT_CELL_UNDERTEMP);
  }

  if (thermistorDecode(max_cell_temp_ever) > TEMP_HIGH_C)
  {
    set_fault_bit(FAULT_CELL_OVERTEMP);
  }
}

void setup()
{
  OCTAL_Set_Clock();

  pinMode(LED, OUTPUT);
  pinMode(PB1, OUTPUT);
  pinMode(PB2, OUTPUT);
  pinMode(PB3, OUTPUT);
  pinMode(PB4, OUTPUT);
  pinMode(PB5, OUTPUT);
  pinMode(PB6, OUTPUT);
  pinMode(PB7, OUTPUT);
  pinMode(PB9, OUTPUT);
  pinMode(PB11, OUTPUT);
  pinMode(PB14, OUTPUT);
  pinMode(PB15, OUTPUT);
  pinMode(PA15, OUTPUT);
  pinMode(CS_PIN, OUTPUT);
  digitalWrite(CS_PIN, HIGH);

  //DISABLE BMS CONTROL OF FETS
  pinMode(PA10, OUTPUT);
  digitalToggle(PA10);

  Serial.begin(115200);

  SPI.begin();
  SPI.beginTransaction(SPISettings(1000000, MSBFIRST, SPI_MODE0));

  init_bms_chip_array();
  init_thermistors();

  initISense();

  #ifdef NORTH
    can_init_bms_north(&hfdcan2);
  #elif defined(EAST)
    can_init_bms_east(&hfdcan2);
  #elif defined(SOUTH)
    can_init_bms_south(&hfdcan2);
  #elif defined(WEST)
    can_init_bms_west(&hfdcan2);
  #endif
}
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
void loop() {
  unsigned long now = millis();

  if (now - ms50 >= 50)
  {
    ms50 = now;

    run_bms_cycle();
  }

  if (now - ms200 >= 200) {
    ms200 = now;

    digitalToggle(PB9);
  }

  delay(1);
}

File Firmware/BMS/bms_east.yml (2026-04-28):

name: bms_east
subscribe:

publish:
  - name: bms_status_east
    id: 0x20
    signals:
      - name: bms_state
        slice: 0 + 3
        unit:
          type: enum
          values:
            - CHARGING_IDLE
            - CHARGING_ACTIVE
            - BALANCING
            - ACTIVE
            - IDLE
            - FAULTED
            - SURVIVAL

      - name: bms_faults
        slice: 3 + 15
        unit:
          type: uint16_t
          name: 
          # Bitfield definition:
          # 0  - CAN error
          # 1  - Loop timing overrun
          # 2  - ADBMS comms fault
          # 3  - ADBMS die over temperature
          # 4  - ADBMS PEC Error
          # 5  - Mux fault
          # 6  - Cell under temp
          # 7  - Cell over temp
          # 8  - Cell undervoltage
          # 9  - Cell overvoltage
          # 10 - Open wire
          # 11 - Current sense fault
          # 12 - Overcurrent
          # 13 - 3.3V brownout
          # 14 - 5V brownout

      - name: pack_voltage
        slice: 18 + 16
        unit:
          type: uint16_t
          name: V
          minimum: 0.0
          maximum: 70.0

      - name: pack_current
        slice: 34 + 10
        unit:
          type: int16_t
          name: A
          minimum: -150.0
          maximum: 400.0

      - name: balancing_mask
        slice: 44 + 14
        unit:
          type: uint16_t
          #Bit is set to 1 if that cell is currently balancing, 0 if not


  - name: bms_temp_metrics_east
    id: 0x21
    signals:
      - name: max_current_cell_temp
        slice: 0 + 10
        unit:
          type: uint16_t
          name: C
          minimum: -20.0
          maximum: 120


      - name: min_current_cell_temp
        slice: 10 + 10
        unit:
          type: uint16_t
          name: C
          minimum: -20.0
          maximum: 120

      - name: max_cell_temp_ever
        slice: 20 + 10
        unit:
          type: uint16_t
          name: C
          minimum: -20.0
          maximum: 120

      - name: min_cell_temp_ever
        slice: 30 + 10
        unit:
          type: uint16_t
          name: C
          minimum: -20.0
          maximum: 120

      - name: temp_threshold_high
        slice: 40 + 10
        unit:
          type: uint16_t
          name: C
          minimum: -20.0
          maximum: 120

      - name: temp_threshold_low
        slice: 50 + 10
        unit:
          type: uint16_t
          name: C
          minimum: -20.0
          maximum: 120


  - name: bms_voltage_metrics_east
    id: 0x22
    signals:
      - name: max_cell_voltage
        slice: 0 + 12
        unit:
          type: uint16_t
          name: V
          minimum: 0
          maximum: 5

      - name: min_cell_voltage
        slice: 12 + 12
        unit:
          type: uint16_t
          name: V
          minimum: 0
          maximum: 5

      - name: cell_voltage_threshold_high
        slice: 24 + 12
        unit:
          type: uint16_t
          name: V
          minimum: 0
          maximum: 5

      - name: cell_voltage_threshold_low
        slice: 36 + 12
        unit:
          type: uint16_t
          name: V
          minimum: 0
          maximum: 5

      - name: charger_target_voltage
        slice: 48 + 12
        unit:
          type: uint16_t
          name: V
          minimum: 0
          maximum: 70


  - name: cell_voltages_0_east
    id: 0x23
    signals:
      - name: cell_1
        slice: 0 + 12
        unit:
          type: uint16_t
          name: V
          minimum: 0
          maximum: 5
      - name: cell_2
        slice: 12 + 12
        unit:
          type: uint16_t
          name: V
          minimum: 0
          maximum: 5
      - name: cell_3
        slice: 24 + 12
        unit:
          type: uint16_t
          name: V
          minimum: 0
          maximum: 5
      - name: cell_4
        slice: 36 + 12
        unit:
          type: uint16_t
          name: V
          minimum: 0
          maximum: 5
      - name: cell_5
        slice: 48 + 12
        unit:
          type: uint16_t
          name: V
          minimum: 0
          maximum: 5


  - name: cell_voltages_1_east
    id: 0x24
    signals:
      - name: cell_6
        slice: 0 + 12
        unit:
          type: uint16_t
          name: V
          minimum: 0
          maximum: 5
      - name: cell_7
        slice: 12 + 12
        unit:
          type: uint16_t
          name: V
          minimum: 0
          maximum: 5
      - name: cell_8
        slice: 24 + 12
        unit:
          type: uint16_t
          name: V
          minimum: 0
          maximum: 5
      - name: cell_9
        slice: 36 + 12
        unit:
          type: uint16_t
          name: V
          minimum: 0
          maximum: 5
      - name: cell_10
        slice: 48 + 12
        unit:
          type: uint16_t
          name: V
          minimum: 0
          maximum: 5
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

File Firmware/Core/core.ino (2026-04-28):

#define HAL_FDCAN_MODULE_ENABLED
#define HAL_CORTEX_MODULE_ENABLED


#include "stm32g4xx_hal.h"
#include "stm32g4xx_hal_fdcan.h"
#include "can_api.h"
#include "MCP23S17.h"

// STM32G473CCTx pin defs
#define HEARTBEAT PA8
#define ASENSE_5V PA0
#define ASENSE_3V3 PA1

#define RESET_IO PA10
#define DISP_CS PA9

#define CAN_COMS PB6 
#define USBC_COMS PB7 
#define BOOT0 PB8 

#define CUBE_HANDOFF PB11 
#define RXCAN PB12 
#define TXCAN PB13 

#define CUBE_IO_RESET PB14 
#define CTRL_NONCRIT_CHECK PB15 
#define SENSE_POWER_CYCLE PA15

// MCP Pin Defs
// port B; all unlabeled are input
#define RESET_CUBE_1 8 // out
#define SHDN_REMOTE 9
#define SHDN_TILT 10
#define SHDN_WIRED 11
#define SHDN_FRAME 12
#define SHDN_TSMS 13
#define SHDN_CRIT_RIDER 14
#define SHDN_CTRL_LOBATT 15

// port A; all unlabeled are input
#define DEBUG1 0 // out
#define RESET_CUBE_2 1 // out
#define SHDN_LOWER_RIDER 3
#define SHDN_NUC 2
#define SHDN_BMS_N 4
#define SHDN_BMS_E 5
#define SHDN_BMS_S 6
#define SHDN_BMS_ALL 7

FDCAN_HandleTypeDef hfdcan2;

// CS, MISO, MOSI, SCK
#define CS PA4
#define MISO PA6
#define MOSI PA7
#define SCK PA5

MCP23S17 MCP(CS);

bool mcpbegin = false;

void OCTAL_Set_Clock(void) {
  // set flash latency for target (144MHz -> FLASH_LATENCY_4) and up voltage to HF range
  __HAL_RCC_PWR_CLK_ENABLE();
  HAL_PWREx_ControlVoltageScaling(PWR_REGULATOR_VOLTAGE_SCALE1_BOOST);

  // Request HSE ON (clock source mode from external high-speed crystal)
  RCC->CR |= RCC_CR_HSEON;

  //Move PLL to source off of HSE
  MODIFY_REG(RCC->CFGR, RCC_CFGR_SW, RCC_CFGR_SW_HSE);

  //Setup PLL for 48MHz peripheral clock
  RCC_OscInitTypeDef RCC_OscInitStruct = { 0 };
  RCC_OscInitStruct.OscillatorType = RCC_OSCILLATORTYPE_HSE;
  RCC_OscInitStruct.HSEState = RCC_HSE_ON;
  RCC_OscInitStruct.PLL.PLLState = RCC_PLL_ON;
  RCC_OscInitStruct.PLL.PLLSource = RCC_PLLSOURCE_HSE;
  RCC_OscInitStruct.PLL.PLLM = RCC_PLLM_DIV4;  // 12MHz after div
  RCC_OscInitStruct.PLL.PLLN = 24;             //2ds88Mhz after mult
  RCC_OscInitStruct.PLL.PLLP = RCC_PLLP_DIV2;  //144MHz CPU clock
  RCC_OscInitStruct.PLL.PLLQ = RCC_PLLQ_DIV6;  //Peripherals at 48MHz (required by USB (48MHz only), CAN ahas a bit more leeway)
  RCC_OscInitStruct.PLL.PLLR = RCC_PLLR_DIV2;
  if (HAL_RCC_OscConfig(&RCC_OscInitStruct) != HAL_OK) {
    Error_Handler();
  }

  //Enable PLL
  SET_BIT(RCC->CR, RCC_CR_PLLON);

  //Set CPU and bus clocks to source 144MHz from PLL
  RCC_ClkInitTypeDef RCC_ClkInitStruct = { 0 };
  RCC_ClkInitStruct.ClockType = RCC_CLOCKTYPE_HCLK | RCC_CLOCKTYPE_SYSCLK
                                | RCC_CLOCKTYPE_PCLK1 | RCC_CLOCKTYPE_PCLK2;
  RCC_ClkInitStruct.SYSCLKSource = RCC_SYSCLKSOURCE_PLLCLK;
  RCC_ClkInitStruct.AHBCLKDivider = RCC_SYSCLK_DIV1;
  RCC_ClkInitStruct.APB1CLKDivider = RCC_HCLK_DIV1;
  RCC_ClkInitStruct.APB2CLKDivider = RCC_HCLK_DIV1;

  if (HAL_RCC_ClockConfig(&RCC_ClkInitStruct, FLASH_LATENCY_4) != HAL_OK) {
    Error_Handler();
  }

  //push new clock settings to time-dependent code/structs
  SystemCoreClockUpdate();

  //Start tick counter
  HAL_InitTick(TICK_INT_PRIORITY);
}

void setup() {
  pinMode(HEARTBEAT, OUTPUT);  // Core Heartbeat
  digitalWrite(HEARTBEAT, HIGH);

  // delay(20000);

  pinMode(RESET_IO, OUTPUT);
  digitalWrite(RESET_IO, HIGH); // SO IMPORTANT TO HAVE BEFORE MCPBEGIN

  pinMode(CUBE_HANDOFF, OUTPUT);
  digitalWrite(CUBE_HANDOFF, LOW);

  Serial.begin(112500);
  delay(5000);

  OCTAL_Set_Clock();
  delay(10);

  pinMode(CAN_COMS, OUTPUT);
  pinMode(USBC_COMS, OUTPUT);
  pinMode(BOOT0, INPUT);

  
  pinMode(RXCAN, INPUT);
  pinMode(TXCAN, OUTPUT);

  // pinMode(CUBE_IO_RESET, OUTPUT);
  pinMode(CTRL_NONCRIT_CHECK, OUTPUT);
  pinMode(SENSE_POWER_CYCLE, OUTPUT);


  pinMode(DISP_CS, OUTPUT);
  digitalWrite(DISP_CS, HIGH);

  SPI.begin();
  // mcpbegin = MCP.begin();
  delay(50);

  if (mcpbegin) {
    MCP.pinMode1(DEBUG1, OUTPUT);
    MCP.pinMode1(RESET_CUBE_2, OUTPUT);

    // GPB output: RESET_CUBE_1
    MCP.pinMode1(RESET_CUBE_1, OUTPUT);

    // everything else input (SHDN signals)
    MCP.pinMode1(SHDN_REMOTE, INPUT);
    MCP.pinMode1(SHDN_TILT, INPUT);
    MCP.pinMode1(SHDN_WIRED, INPUT);
    MCP.pinMode1(SHDN_FRAME, INPUT);
    MCP.pinMode1(SHDN_TSMS, INPUT);
    MCP.pinMode1(SHDN_CRIT_RIDER, INPUT);
    MCP.pinMode1(SHDN_CTRL_LOBATT, INPUT);

    MCP.pinMode1(SHDN_LOWER_RIDER, INPUT);
    MCP.pinMode1(SHDN_NUC, INPUT);
    MCP.pinMode1(SHDN_BMS_N, INPUT);
    MCP.pinMode1(SHDN_BMS_E, INPUT);
    MCP.pinMode1(SHDN_BMS_S, INPUT);
    MCP.pinMode1(SHDN_BMS_ALL, INPUT);
    // // Port 0 (GPA): Debug GPA0, ResetCube2 GPA1 are Outputs (0), others are SHDN Inputs (1)
    // MCP.pinMode8(0, 0b11111100);   
    // // Port 1 (GPB): ResetCube1 GPB0 is Output (0), others are SHDN Inputs (1)
    // MCP.pinMode8(1, 0b11111110); 
  
    Serial.println("MCP23S17 Initialized.");
  } else {
    Serial.println("MCP23S17 not found.");
  }

  can_init_core(&hfdcan2);
}

uint16_t parsedValue = 0;
float current_5v = 0;
float current_3v3 = 0;

// const int shdnPins[] = {
//   SHDN_N, SHDN_NE, SHDN_E, SHDN_SE, 
//   SHDN_S, SHDN_SW, SHDN_W, SHDN_NW
// };
// const char* shdnLabels[] = {
//   "N ", "NE", "E ", "SE", 
//   "S ", "SW", "W ", "NW"
// };

void printShutdownStatus() {
    if (mcpbegin) {
    Serial.println("--- MCP SHDN Status ---");

    const int mcpPins[] = {
      SHDN_REMOTE,
      SHDN_TILT,
      SHDN_WIRED,
      SHDN_FRAME,
      SHDN_TSMS,
      SHDN_CRIT_RIDER,
      SHDN_CTRL_LOBATT,

      SHDN_LOWER_RIDER,
      SHDN_NUC,
      SHDN_BMS_N,
      SHDN_BMS_E,
      SHDN_BMS_S,
      SHDN_BMS_ALL
    };

    const char* mcpLabels[] = {
      "REMOTE",
      "TILT",
      "WIRED",
      "FRAME",
      "TSMS",
      "CRIT",
      "LOBATT",

      "LOWER",
      "NUC",
      "BMS_N",
      "BMS_E",
      "BMS_S",
      "BMS_ALL"
    };

    for (int i = 0; i < 13; i++) {
      int state = MCP.read1(mcpPins[i]);

      Serial.print(mcpLabels[i]);
      Serial.print(": ");
      Serial.print(state == HIGH ? "CLOSED" : "OPEN");

      if ((i + 1) % 4 == 0) {
        Serial.println();
      } else {
        Serial.print(" | ");
      }
    }

    Serial.println();
  }
  Serial.println();
}
float MAX_VPACK_DIFF = 0.080; // 80mV pack difference
bool try_to_reset = true;
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

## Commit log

2025-11-02 adding logical gate structure without RC components in bus arbitration logic sch file
    [bus_arbitration_logic.kicad_sch, can_repeater.kicad_sch, flight-core.kicad_sch]
2025-11-04 moving multi-unit parts into OlinBAD library; added 0603 0.1uF cap
    [bus_arbitration_logic.kicad_sch, can_repeater.kicad_sch, flight-core.kicad_sch]
2025-11-07 BMS updates, power/fet final updates
    [HIghSidePowerFET.kicad_pcb, HIghSidePowerFET.kicad_sch, Power Board.kicad_pcb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]
2025-11-07 bms updates (for real this time)
    [bms.kicad_pcb]
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2025-11-07 Removed images, added 3.3V and 5V hierarchical inputs, added second pair of decoupling caps
    [bus_arbitration_logic.kicad_sch, can_repeater.kicad_sch]
2025-11-07 added many shutdown nodes, can_repeater instances, separated arm_connectors, basic stm32 peripherals
    [arm_connectors.kicad_sch, flight-core.kicad_sch, stm32.kicad_sch]
2025-11-08 renaming the values of LRC generics to just the value with unit letter (except resistors are just the value)
    [bus_arbitration_logic.kicad_sch, can_repeater.kicad_sch, flight-core.kicad_sch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]
2025-11-12 bms gotten to 0 unrouted traces!
    [ADBMS1818.kicad_sch, bms.kicad_sch, cell_tps.kicad_sch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]
2025-11-12 adding full chain of shutdown nodes
    [flight-core.kicad_sch, stm32.kicad_sch]
2025-11-13 moving non-battery shdn nodes, power supplies and cube header into hierarchical sheets; added current sensors
    [converters.kicad_sch, cube_1.kicad_sch, shdn.kicad_sch]
2025-11-13 moved termination resistors into arm connector, added current sense and spi io extender parts
    [arm_connectors.kicad_sch]
2025-11-13 added reorganized main schematic and created draft of test_points_leds in stm32
    [flight-core.kicad_sch, stm32.kicad_sch, test_points_leds.kicad_sch]
2025-11-13 reorganized stm32 schematic, moved usbc to hierarchical
    [stm32.kicad_sch, usbc.kicad_sch]
2025-11-14 added all cube pins and corrected cube shdn node
    [cube_1.kicad_sch, shdn.kicad_sch]
2025-11-14 added 5V to USBC VBUS to power by usb; edited stm32 file to match
    [stm32.kicad_sch, usbc.kicad_sch]
2025-11-14 added common mode filter on CAN term resistor; renamed cube_ok
    [arm_connectors.kicad_sch, converters.kicad_sch, flight-core.kicad_sch]
2025-11-15 FAB updates to the BMS, power board, and fet board
    [Power Board-B_Cu.gbl, Power Board-B_Mask.gbs, Power Board-B_Paste.gbp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]
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2025-11-19 removed 5.1k resistor to eliminate usb logic
    [usbc.kicad_sch]
2025-11-19 changed tcan to HGVDR variety, changed termination R schematics
    [can_repeater.kicad_sch]
2025-11-19 fixing incorrect value name for tcan HG part
    [can_repeater.kicad_sch]
2025-11-19 added test points and LEDs; color inaccurate
    [test_points_leds.kicad_sch]
2025-11-19 adding in-progress converter enable; in-lined shunt resistors, source 5V from USB, LEDs moved
    [converters.kicad_sch]
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2025-11-19 updated boot0 & hierarchical LED sheet, connected all io, added display & reorganized
    [stm32.kicad_sch]
2025-11-19 removed old MATE shdn nodes, added BMS_EN, reorganized and shrunk sheet size
    [flight-core.kicad_sch]
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2025-11-25 fab updates to bms, power board, fet board
    [ADBMS1818.kicad_sch, Power Board.kicad_pcb, bms.kicad_sch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]
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2025-11-27 added buzzer step file, 2x7 and 2x4 microfit footprints
2025-11-27 minor erc fixes (grid, reannotation, updated footprint associations)
    [bus_arbitration_logic.kicad_sch, can_repeater.kicad_sch, converters.kicad_sch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]
2025-11-27 ERC fixes + reset cube signal
    [cube_1.kicad_sch, stm32.kicad_sch]
2025-11-27 corrected CAN+ CAN- accidental connection, added reset_cube
    [flight-core.kicad_sch]
2025-11-27 adding passive buzzer, moving buzzer to gpio pin
    [cube_1.kicad_sch]
2025-11-27 importeed bms board settings and began rerouting repeater
    [cube_1.kicad_sch]
2025-11-30 added sense pwr cycle pull down, low side cube mosfets, fixed mosi/miso swap on i/o expander, Rs -> generic, reannotated
    [can_repeater.kicad_sch, converters.kicad_sch, cube_1.kicad_sch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]
2025-11-30 completed can repeater layout, swapped gate pins for layout convenience
    [bus_arbitration_logic.kicad_sch]
2025-11-30 added missing mosi pin
    [stm32.kicad_sch]
2025-11-30 replicated layout for all can repeaters, placed in shutdown order; added rider lower estop in schem; j18 is 4 pin
    [cube_1.kicad_sch, shdn.kicad_sch, stm32.kicad_sch]
2025-12-04 major component area placement begun, installing place footprints plugin, updating connectors to vertical
    [bus_arbitration_logic.kicad_sch, can_repeater.kicad_sch, converters.kicad_sch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]
2025-12-05 can repeater placement, custom cube footprint, connector placement
    [Bottom Of Cube.dxf, flight-core.kicad_sch, motherboard.dxf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]
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2025-12-11 update to some firmware stuff and updates/fab stuff for the thermsitor board
    [Thermistors-B_Cu.gbr, Thermistors-B_Mask.gbr, Thermistors-B_Paste.gbr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]
2025-12-29 swapped 5 & 6 in bus arb, placed components
    [bus_arbitration_logic.kicad_sch, stm32.kicad_sch]
2025-12-30 tightened up arbitrator layout
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2025-12-31 switching test points to correct footprint and alternative symbol, moving leds
    [cube_1.kicad_sch, shdn_led.kicad_sch, test_points_leds.kicad_sch]
2025-12-31 recentered molex footprint, corrected arm connector positionings
2026-01-02 updating mini tps to new symbol and footprint
    [cube_1.kicad_sch, flight-core.kicad_sch, shdn_led.kicad_sch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]
2026-01-02 corrected shdn fp connector, more led and can repeater placement
    [shdn.kicad_sch]
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2026-01-07 Swapped AND gate inputs for layouting
    [bus_arbitration_logic.kicad_sch, can_repeater.kicad_sch]
2026-01-07 removed extra test points, removed debug2, reannotated schem
    [bus_arbitration_logic.kicad_sch, can_repeater.kicad_sch, converters.kicad_sch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]
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2026-01-07 basics of CAN and some STM init firmware. Also updated very minor BMS things
    [fans.kicad_sch]
2026-01-15 batt power planes, connector side correction, and savepoint before I move every repeater
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2026-01-15 routed almost everything except 3.3V power and CAN+/-
    [stm32.kicad_sch]
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2026-01-15 everything but CAN repeater GND issue and CAN+/-
2026-01-16 corrected footprint courtyard issues
2026-01-16 fixed new silkscreen and courtyard drc errors, flipped middle connector
    [flight-core.kicad_sch]
2026-01-16 added more silkscreen and flipped some connectors (all connectors now point to the back)
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2026-02-27 CAN library working with dbc, yml, for extended and standard IDs. Core finalized. BMS firmware bringup started
    [power.kicad_sch]
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2026-03-04 updated BMS firmware and created Charger PCB filesx
    [Charger.kicad_pcb, Charger.kicad_sch, converters.kicad_sch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]
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2026-03-06 built charger schematic and added parts to layout
    [Charger.kicad_pcb, Charger.kicad_sch, converters.kicad_sch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]
2026-03-07 Added: Contactor control, Voltage sense, I2C comms for oled screen, 3v3 and 5v converters, power switch
    [3V3_Converter.kicad_sch, 5V_Converter.kicad_sch, Charger.kicad_sch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]
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2026-03-16 edits to charger and made ground ring bodge board. Both ready for PCB fab
    [Charger.kicad_pcb, Charger.kicad_sch, GroundRing.kicad_pcb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]
2026-03-16 unrouted cube flipper
    [flipper.kicad_pcb, flipper.kicad_sch]
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2026-03-17 complete flipper i really hope I didn't cook it
    [flipper.kicad_pcb, flipper.kicad_sch]
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2026-04-28 fixed reboot cube fight and mcp.write1 issue, still need to figure out intentional cube reset
    [core.ino]
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2026-04-28 Resolved conflicts by accepting all remote (core) changes
    [BMS.ino, bms_east.yml, bms_north.yml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]
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
